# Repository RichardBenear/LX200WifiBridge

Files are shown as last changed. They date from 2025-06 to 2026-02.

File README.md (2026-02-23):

# LX200 WiFi Bridge for DDScopeX

This project implements a WiFi bridge that allows **SkySafari Plus/Pro** and **Stellarium Mobile** to control a telescope running [DDScopeX/OnStepX](https://github.com/richardbenear/DDScopeX) via the **LX200 protocol**.

It runs on a **Seeed Studio XIAO ESP32-C3** and acts as an LX200 server over WiFi, forwarding commands to a **Teensy 4.1** via UART (`Serial1`). The Teensy responds with appropriate data, which is relayed back to the client app.

This project requires the compatible version of DDScopeX which has the LX200 Handler code (LX200Handler.cpp) since the handshaking and communication connection is handled there.

---

## 💡 Features

- **WiFi Access Point + Station Mode**  
  Connects to Stellarium and SkySafari as an AP and optionally joins an existing WiFi network for dual communication.

- **LX200 Command Forwarding**  
  Forwards commands to DDScopeX/OnStepX over Serial1, handles custom formatting quirks for compatibility (e.g. `:SC`, `:SG+06.0#`).

- **Custom Application Commands**  
  Replies directly to a few app-specific commands such as:
  - `:GVP#` → `OnStepX.DDScopeX#`
  - `:GVN#` → `2.0#`
  - `:GVD#` → `May 2025#`
  
  Handles other communication "quirks" in both Stellarium Mobile and Sky Safari Plus/Pro.

- **Oled Status Display**  
  Shows both the ESP32 AP IP and the IP of the WiFi Display device connected to the Teensy.

- **Reset Trigger from Teensy**  
  Supports a software-reset via a GPIO input from the Teensy (`D10` / `RESET_PIN`).

---

## 📡 Network Configuration

- **Access Point (AP)**
  - SSID: `LX200-ESP32`
  - Password: `password`
  - Static IP: `192.168.4.1`
  - Port: `4030` (standard LX200 TCP port)

- **Station Mode**
  - Credentials pulled from `secrets.h`
  - IP displayed on the OLED

---

## 🔌 Hardware Connections

| ESP32-C3 Pin | Function | Description |
|---|---|---|
| `D6` | `TX` | To Teensy RX (Serial8) |
| `D7` | `RX` | From Teensy TX (Serial8) |
| `D10` | `RESET_PIN` | From Teensy for soft reset |
| `D4/D5` | I2C SDA/SCL | OLED display (optional) |

---

## 📁 File Structure

| File | Purpose |
|---|---|
| `src/LX200WifiBridge.cpp` | Main command forwarding logic |
| `include/secrets.h` | WiFi credentials (ignored in Git) |
| `include/secretsTemplate.h` | Example secrets file for users |
| `src/OledDisplay.*` | OLED display handling (I2C, optional) |

## Book: BUILD A DIRECT DRIVE TELESCOPE: A Comprehensive Guide
Book Available on Amazon [Here](https://a.co/d/0cUrQWGB) 

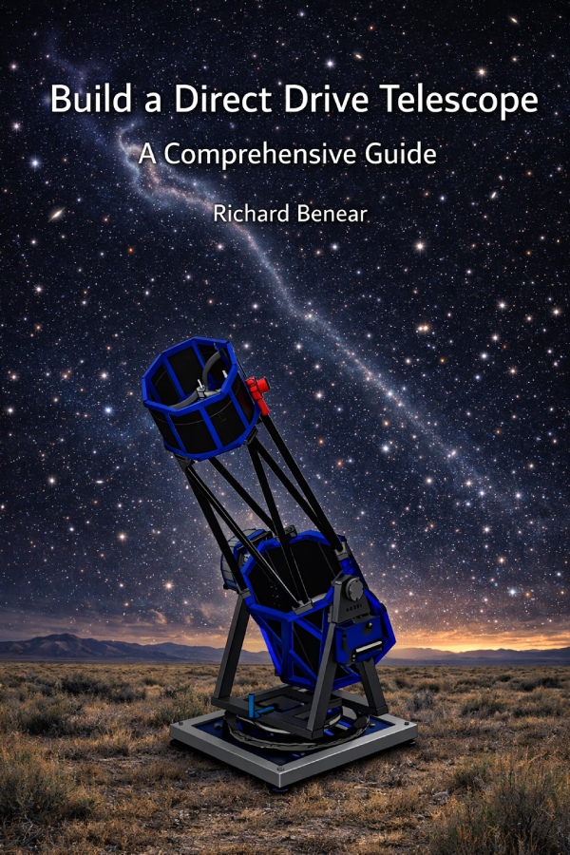
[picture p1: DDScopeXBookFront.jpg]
DDScopeX Book Front


---

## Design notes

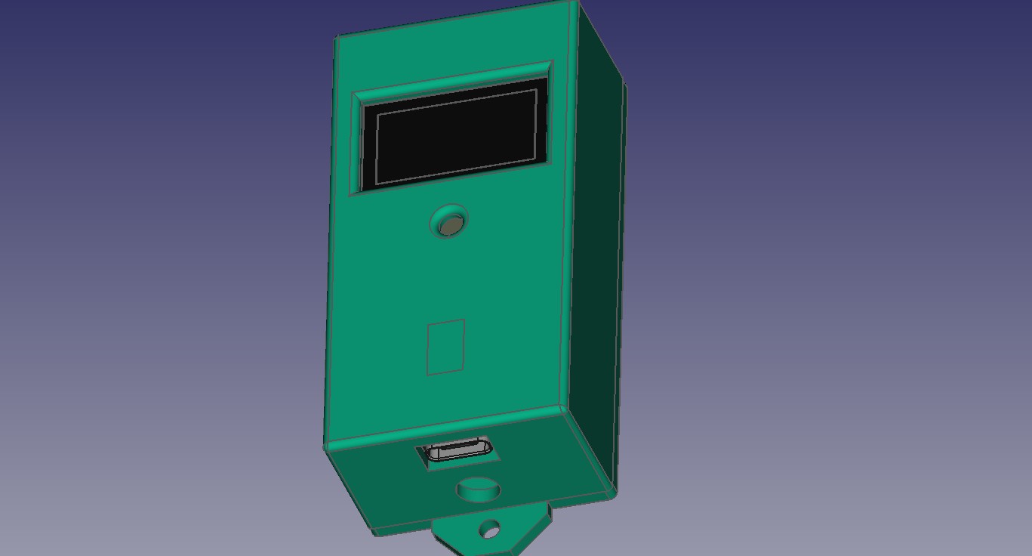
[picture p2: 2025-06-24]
LX200BridgeBox.jpg

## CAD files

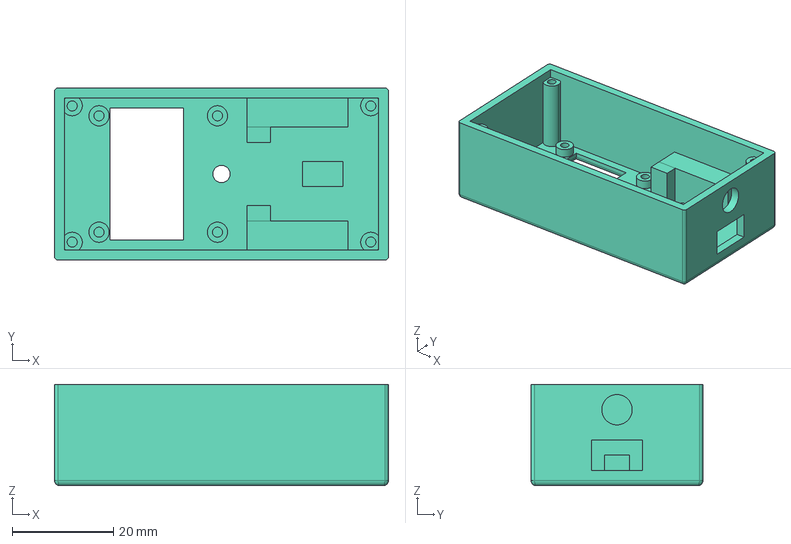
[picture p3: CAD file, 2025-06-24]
LX200_wifi_box-shell.step
66.0 x 34.0 x 20.0 mm

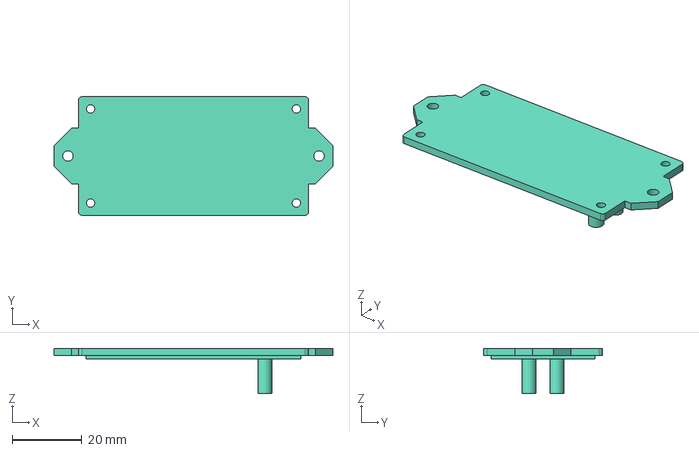
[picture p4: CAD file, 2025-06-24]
LX200_wifi_box-Lid.step
80.0 x 34.0 x 13.0 mm

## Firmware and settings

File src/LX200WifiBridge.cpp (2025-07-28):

// ========================================
// ======== LX200 Command Processor =======
// ========================================
// Author: Richard Benear 5/25
//
// Runs on a SEEED XIAO ESP32-C3 processor with external antenna.
// Adds SkySafari and Stellarium capability to the DDScopeX project.
//
// Connects via wifi to Sky Safari Plus/Pro or Stellarium Mobile clien.
//    Sends the LX200 protocol commands to Teensy Serial8 via ESP32C3 Serial1. 
//    Teensy responds with data which is relayed to Wifi Client Sky Safari
//    or Stellarium Mobile.
//
//  Note: Originally, I tried integrating this code with the WiFi Hand
//    Controller (screen mirror) code that runs on the ESP32-S3 and is
//    connected to Teensy via USB. Multiple tasks running at different rates
//    required extensive use of semaphores and additional complexity for
//    debugging since the USB Serial was shared. Performance was not very
//    good either, so this separate ESP32-C3 implementation is cleaner.
//

#include <Arduino.h>
#include <WiFi.h>
#include <WiFiServer.h>
#include <Wire.h>
#include "OledDisplay.h"
#include "esp_wifi.h"
#include "soc/soc.h"
#include "soc/rtc_cntl_reg.h"
#include "../include/secrets.h"

#define LX200_AP_SSID             "LX200-ESP32"
#define LX200_AP_PASSWORD            "password"
#define LX200_AP_IP_ADDR          {192,168,4,1} 
#define LX200_AP_GW_ADDR          {192,168,4,1} 
#define WIFI_DISPLAY_AP_IP_ADDR   {192,168,4,2} 

#define SERIAL_TEENSY Serial1
#define SERIAL_DEBUG Serial

#define I2C_SDA D4 
#define I2C_SCL D5 
#define RESET_PIN D10 

#define TEENSY_ACK_TIMEOUT 500

WiFiServer lx200Server(4030);

static bool receivingLX200 = false;
volatile bool clientConnected = false;
static int hashCount = 0;

// Check for LX200 commands that need no response to client
bool isNoResponseCommand(const String &cmd) {
  return (
    cmd == ":Me#"  ||  // Start moving East
    cmd == ":Mn#"  ||  // Start moving North
    cmd == ":Ms#"  ||  // Start moving South
    cmd == ":Mw#"  ||  // Start moving West
    cmd == ":Qe#"  ||  // Abort slew East
    cmd == ":Qn#"  ||  // Abort slew North
    cmd == ":Qs#"  ||  // Abort slew South
    cmd == ":Qw#"  ||  // Abort slew West
    cmd == ":RC#"  ||  // Set slew rate to centering
    cmd == ":RF#"  ||  // Set slew rate to fast
    cmd == ":RG#"  ||  // Set slew rate to guiding
    cmd == ":RM#"  ||  // Set slew rate to find
    cmd == ":RS#"  ||  // Set slew rate to max, or Sync for LX200 classic
    cmd == ":W1#"  ||  // Set site 1
    cmd == ":CS#"      // Synchronize the telescope with current RA/DEC
  );
}

// Check for LX200 commands that are Specific to this App
String checkForAppSpecificCmds(const String &cmd) {
  if (cmd == ":GVP#")  return "On-Step#";//"OnStepX.DDScopeX#"; // Product Name
  if (cmd == ":GVN#")  return "2.0#";        // Firmware Version
  if (cmd == ":GVD#")  return "May 2025#";   // Firmware Date
  if (cmd == ":GVT#")  return "08:02:00#";   // Telescope Firmware time
  //if (cmd == ":D#")    return "#";         // Requests a string of bars indicating the distance to the current target location
  //if (cmd == ":CM#")   return "Syncd Object#"; 
  //if (cmd == ":GW#")   return "AN1#";      // Get Scope alignment status <mount><tracking><alignment>
                                             //   mount: A-AzEl mounted, P-Equatorially mounted, G-german mounted equatorial
                                             //   tracking: T-tracking, N-not tracking
                                             //   alignment: 0-needs alignment, 1-one star aligned, 2-two star aligned, 3-three star aligned
  return "";
}

// :MS#   returns:
    //              0=Goto is possible
    //              1=below the horizon limit
    //              2=above overhead limit
    //              3=controller in standby
    //              4=mount is parked
    //              5=Goto in progress
    //              6=outside limits (AXIS2_LIMIT_MAX, AXIS2_LIMIT_MIN, AXIS1_LIMIT_MIN/MAX, MERIDIAN_E/W)
    //              7=hardware fault
    //              8=already in motion
    //              9=unspecified error

const char* getAsciiLabel(uint8_t c) {
  static char label[4];  // must be static to return a valid pointer

  switch (c) {
    case '\r': return "\\r";
    case '\n': return "\\n";
    case '\t': return "\\t";
    default:
      if (isprint(c)) {
        label[0] = (char)c;
        label[1] = '\0';
        return label;
      } else {
        return ".";
      }
  }
}

// ================ Handshake Teensy =====================
// Handshake Teensy: Send 'L' and wait for 'K'
void handshakeTeensy() {
  SERIAL_TEENSY.write('L');
  SERIAL_TEENSY.flush();

  unsigned long ackStart = millis();
  while ((millis() - ackStart) < TEENSY_ACK_TIMEOUT) {
    if (SERIAL_TEENSY.available() && SERIAL_TEENSY.read() == 'K') {
      delay(3);
      // Flush any remaining pre-response garbage
      while (SERIAL_TEENSY.available()) SERIAL_TEENSY.read();
      break;
    }
  }
}

// ============= Read Teensy Response =====================
String readTeensyResponse() {
  String tResponse = "";
  unsigned long startWait = millis();

  // Wait for at least 1 byte
  while ((millis() - startWait) < 2300) {
    if (SERIAL_TEENSY.available()) break;
  }

  if (!SERIAL_TEENSY.available()) {
    SERIAL_DEBUG.println("Timeout waiting for response ':'");
    return "";  // Return minimal terminator to avoid client crash
  }

  // Read until '#' is received or timeout
  unsigned long readStart = millis();
  while ((millis() - readStart) < 450) {
    while (SERIAL_TEENSY.available()) {
      char rc = SERIAL_TEENSY.read();

      // Skip early junk like stray 'K', '\n', etc.
      if (rc == 'K' || rc == '\n' || rc == '\r') continue;

      tResponse += rc;
      if (rc == '#') {
        return tResponse;
      }
    }
  }

  SERIAL_DEBUG.println("Timeout waiting for Teensy response '#'");
  return tResponse;  // Might be partial
}

/// =============Process LX200 Command =====================
// Process the LX200 incoming command and determine if it needs to be
//    fetched from Teensy, no return, or return a special string from here.
String processLX200Command(const String &cmd) {

  String localResp = checkForAppSpecificCmds(cmd);
  if (localResp.length() != 0) return localResp;

  String truncCmd = cmd;  // make a mutable copy

  //Handle Specific: SkySafari is sending an unsupported format for timezone in OnStep
  //so truncate the decimal
  if (cmd == ":SG+06.0#") {
    int dotIndex = truncCmd.indexOf('.');
    int hashIndex = truncCmd.indexOf('#');

    if (dotIndex != -1 && hashIndex != -1 && dotIndex < hashIndex) {
      truncCmd = truncCmd.substring(0, dotIndex) + truncCmd.substring(hashIndex);
    }
  }

  //SERIAL_DEBUG.print("truncCmd="); SERIAL_DEBUG.println(truncCmd);
  handshakeTeensy();
  SERIAL_TEENSY.print(truncCmd);
  SERIAL_TEENSY.flush();
  return readTeensyResponse();
}

// ============== Handle LX200 CLient =====================
void handleLX200Client() {
  WiFiClient client = lx200Server.available();

  if (!client || !client.connected()) return;
  client.setNoDelay(true);  // <-- important
  String lx200Cmd = "";
  bool receivingCmd = false;
  unsigned long start = millis();

  // Not sure of the exact minimum for timeout but 10 sec works all the time
  while (client.connected()) {
    if (millis() - start > 10000) {
      SERIAL_DEBUG.println("[LX200] Client timeout.");
      break;
    }
    while (client.available()) {
      start = millis();  // Reset timeout on each byte
      char c = client.read();
      //Serial.printf("Received from client, byte: 0x%02X (%s)\n", (uint8_t)c, getAsciiLabel((uint8_t)c));

      // Stellarium Mobile sends 0x06 to check for LX200 mount type
      if (c == 0x06) {
        client.print('A');
        client.flush();
        SERIAL_DEBUG.println("Sent 'A'");
        continue;
      }

      // Wait for ':' to begin a new command, Stellarium mobile puts a '#' in front of ':' many times
      if (!receivingCmd && c == ':') {
        receivingCmd = true;
        lx200Cmd = ":";
        continue;
      }

      lx200Cmd += c;

      if (c == '#' && receivingCmd) {
        receivingCmd = false;

        String response = processLX200Command(lx200Cmd);

         // Remove hash from bool responses
        if ((response == "1#" || response == "0#") && lx200Cmd != ":MS#") {
          response = response.substring(0, 1);
        }

        // must use break; here and not return; or SkySafari disconnects
        // because of the :RS# command, which returns nothing, is immediately
        // followed by the client sending another command and the while loop must         
        // get ready for next command quickly or misses the command. (e.g. :GD#)
        if (isNoResponseCommand(lx200Cmd)) {
          SERIAL_DEBUG.printf("Skipping response for: %s\n", lx200Cmd.c_str());
          break;
        }

        if (response.length() > 0) {
          // Stellarium wants this string and not the OnStep reply of "1#"
          // So the :SC command was sent to OnStep but here we return this string instead.
          if (lx200Cmd.startsWith(":SC")) {
            response = "1Updating Planetary Data#          #";
          }

          // You MUST return a '1' ('#' get's stripped later) for Stellarium GOTO
          // OnStepX returns nothing, just a '#'.
          if (lx200Cmd == ":Q#") {
            response = "1";
          }

          client.write((const uint8_t *)response.c_str(), response.length());
          client.flush();
          SERIAL_DEBUG.printf("CmdFromClient: %-13s  RespToClient: %s\n", lx200Cmd.c_str(), response.c_str());
        }
      }
    }
    yield();  // helps WiFi stack
  }
}

// =================== SETUP =====================
void setup() {
  
  delay(5000);  // this here to allow time to get the debug terminal going

  SERIAL_DEBUG.begin(115200);
  SERIAL_DEBUG.println("Debug port started");

  // SERIAL_TEENSY.begin(460800, SERIAL_8N1, D7, D6);
  SERIAL_TEENSY.begin(230400, SERIAL_8N1, D7, D6); //D7=RX, D6=TX

  pinMode(RESET_PIN, INPUT_PULLUP);

  delay(5);
  // Disable brownout detector on the WeMos ESP32 D1 Mini if that is hardware used
  // WRITE_PERI_REG(RTC_CNTL_BROWN_OUT_REG, 0); //disable brownout detector

  Serial.println("Starting TEENSY serial...");
  delay(100);

  while (SERIAL_TEENSY.available()) SERIAL_TEENSY.read();  // Flush junk

  // Initialize I2C on the ESP32-C3's default pins
  initOledDisplay();

  // Using Dual mode Wifi
  WiFi.mode(WIFI_AP_STA);

  // Start Station Mode WiFi
  WiFi.begin(LX200_STA_SSID, LX200_STA_PASSWORD);
  while (WiFi.status() != WL_CONNECTED) {
    delay(500);
    SERIAL_DEBUG.print(".");
  }

  IPAddress lxStaIpMsg = WiFi.localIP();
  SERIAL_DEBUG.print("\nSTA IP Address: ");
  SERIAL_DEBUG.println(lxStaIpMsg);

  delay(10);

  WiFi.setSleep(false);  // Prevent disconnects

  // Set static AP IP
  WiFi.softAPConfig(
    IPAddress(LX200_AP_IP_ADDR), 
    IPAddress(LX200_AP_GW_ADDR), 
    IPAddress(255,255,255,0));

  // Now start AP :  Channel 1, hidden SSID off, max 1 client
  bool apStarted = WiFi.softAP(LX200_AP_SSID, LX200_AP_PASSWORD, 1, 0, 1);
  if (!apStarted) {
    SERIAL_DEBUG.println("Failed to start Access Point!");
  } else {
    SERIAL_DEBUG.println("Access Point started");
  }

  // Print AP IP address
  IPAddress lxApIpMsg = WiFi.softAPIP();
  SERIAL_DEBUG.print("AP IP Address: ");
  SERIAL_DEBUG.println(lxApIpMsg);

  // Start TCP server
  lx200Server.begin();
  SERIAL_DEBUG.println("LX200 TCP Server started on port 4030");
  Serial.printf("WiFi RSSI: %d dBm\n", WiFi.RSSI());

  WiFi.setTxPower(WIFI_POWER_19_5dBm);  // Max power 
}

// ====================== LOOP =======================
unsigned long lastWifiIpCheck = 0;
bool wifiIpReceived = false;
IPAddress wdStaIp;

void loop() {
  handleLX200Client();
  yield();

  // Check for the IP Address of the Wifi Display ESP32 and display it on the OLED
  if (!wifiIpReceived && millis() - lastWifiIpCheck >= 15000) {
    lastWifiIpCheck = millis();
    
    String wdStaIpMsg = processLX200Command(":GI#");
    Serial.print("wdStaIpMsg = "); Serial.println(wdStaIpMsg);

    // Only proceed if it is long enough and ends with '#'
    if (wdStaIpMsg.length() > 4 && wdStaIpMsg.endsWith("#")) {
      wdStaIpMsg.remove(wdStaIpMsg.length() - 1); // remove trailing '#'
      wdStaIpMsg.trim();                          // remove newline/whitespace

      IPAddress lxStaIpMsg = WiFi.localIP();
      updateOledDisplay(lxStaIpMsg, LX200_AP_IP_ADDR, wdStaIpMsg, WIFI_DISPLAY_AP_IP_ADDR);
      wifiIpReceived = true;  // Uncomment if you want to stop polling
      Serial.print("got the IP Address from Teensy");
    }
  }

  // Software generated Reset from Teensy
  if (digitalRead(RESET_PIN) == LOW) {
    SERIAL_DEBUG.println("Reset requested from Teensy");
    esp_restart();
  }
}

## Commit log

2025-06-25 fixed power-up lack of sync for IP address over serial
    [LX200WifiBridge.cpp]
2025-07-06 added more delay when fetching IP from Teensy
2025-07-28 made changes necessary for ASCOM driver
